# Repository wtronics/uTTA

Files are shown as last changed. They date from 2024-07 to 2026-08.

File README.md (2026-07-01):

# uTTA — The Micro ($\mu$) Thermal Transient Analyzer

## What's this TTA stuff anyhow?

Thermal Transient Analysis (TTA) is an advanced technique used to determine the thermal impedance model of a cooling path by measuring its thermal step response. This method is rigorously specified in the **JESD 51-14** standard and is brilliantly summarized in the following tutorials:
* [Transient thermal measurements and thermal equivalent circuit models](https://www.infineon.com/dgdl/Infineon-Thermal_equivalent_circuit_models-ApplicationNotes-v01_02-EN.pdf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) *(Highly recommended!)*
* [Structure function based evaluation of the thermal behavior of an LED](https://repository.tugraz.at/publications/1bz3b-q3w35) *(Definitely worth to read)*

Ideally, after completing a measurement, you should be able to transform the raw captured data into a thermal impedance ($Z_{th}$) curve—a staple graph found in almost every power semiconductor datasheet. In a nutshell, a $Z_{th}$ curve allows engineers to read the specific thermal resistance encountered by a device when a rectangular power pulse of a given duration $x$ is applied. By combining this thermal resistance with the dissipated power, you can calculate the exact junction temperature of the semiconductor at the end of that pulse. 

However, this math only holds true as long as the power pulse is brief enough not to hit the physical thermal boundaries of the semiconductor package itself. Once the heat propagates past those boundaries and into the rest of the assembly, you need a dedicated thermal impedance curve tailored to your specific, real-world cooling path. Nexperia published an excellent application note diving deeper into this topic: 
* [Nexperia AN11156](https://assets.nexperia.com/documents/application-note/AN11156.pdf)

Things get significantly more complicated when dealing with non-rectangular power pulses. While an "extended rectangular" approximation works for a rough estimate, it demands a massive amount of manual effort. Furthermore, if your ultimate goal is running a dynamic thermal simulation, static datasheet graphs are practically useless. For simulation purposes, the most elegant approach is to model the thermal cooling path using a network of RC circuits that mimic the system's heating and cooling behavior. Again, Nexperia offers a fantastic guide on how this is done: 
* [Nexperia AN11261](https://assets.nexperia.com/documents/application-note/AN11261.pdf)

But how do you actually extract these RC models for a specific power semiconductor combined with a custom heatsink? This is where the real headache begins. While you might occasionally find thermal models for a MOSFET, they are almost exclusively provided as encrypted SPICE models. Nexperia is one of the few refreshing exceptions, sometimes offering open thermal equivalent RC networks (structured as either Foster or Cauer models). But when it comes to the heatsink, manufacturers typically provide nothing more than a single, static thermal resistance value.

---

## How to perform these measurements?
### The Proper (and Expensive) Way
Capturing high-fidelity thermal transient measurements requires highly specialized hardware. The industry standard system is called **T3Ster**, originally engineered by MicReD (a Hungarian company later acquired by Siemens). 

Unsurprisingly, industrial equipment like this costs an absolute fortune—well into the high 5-to-6-figure Euro range. Because such professional tools are completely inaccessible for hobbyist or educational budgets, I set out to design and build my own miniature alternative.

### My own little Thermal Transient Analyzer (uTTA)
uTTA began as a passion project during the first COVID-19 lockdown. At the time, I was experimenting heavily with various power electronics (mostly MOSFET-based power switches and electronic loads) and kept running into the exact same wall: *How long can I dissipate a specific amount of surge power in this MOSFET before it reaches its critical destructive temperature?*

While several theoretical methods exist to solve this, every single one of them requires you to know the exact thermal impedance curve of your unique mechanical setup.

#### Target Picture
The following checklist outlines the core objectives of this project and what has been successfully accomplished so far:
* [x] **Measurement Hardware:** Design a hardware platform capable of performing single-channel thermal impedance measurements while simultaneously monitoring at least 2 additional channels for future thermal coupling analysis.
* [x] **Postprocessing Software:** Build a software toolkit to process raw measurement data and extract clean thermal impedance ($Z_{th}$) curves.
* [x] **Thermal Coupling:** Add software/hardware support to measure thermal coupling between adjacent semiconductors.
* [x] **Self-Calibration:** Implement software utilities to calibrate the internal measurement hardware.
* [ ] **Time Constant Spectra:** Implement the ability to calculate the time constant spectrum of the $Z_{th}$ curve via the NID (Network Identification by Deconvolution) method (utilizing either classical FFT deconvolution or a Bayesian approach).
* [ ] **RC Model Extraction:** Automatically extract equivalent RC thermal networks directly from the calculated time constant spectrum.
* [x] **Junction Calibration:** Develop software and hardware tools to calibrate the temperature coefficient of the junction under test.
* [ ] **Hardware Simulator:** Build a dedicated hardware simulator capable of generating highly predictable and repeatable cooling curves to rigorously validate all subsequent software processing steps.

#### Design Requirements
The device must adhere to the following constraints:
* **User-Friendly:** It should be straightforward and intuitive to operate.
* **Cost-Effective:** Extremely cheap and easy to replicate. Target budget: **€150** covering all components and the PCB.
* **Highly Available:** Rely exclusively on off-the-shelf components; absolutely no hard-to-find or "unobtanium" parts.
* **High-Current Handling:** Integrate an onboard heating current switch rated for up to 15A DC which could be upgraded to even higher heating currents.
* **Auxiliary Sensing:** Include a few Type-K thermocouple interfaces for low-speed ambient/heatsink monitoring (< 5 Samples/s).
* **Multi-Junction Tracking:** Capable of measuring the primary Junction Under Test (JUT) alongside 2 secondary monitoring junctions to evaluate thermal coupling.
* **Dynamic Range Optimization:** Provide software-selectable gain settings for the JUT monitor to maximize ADC resolution throughout the transient event.
* **High-Speed Sampling Speed:** Deliver an ultra-fast sampling rate of at least 1MS/s immediately following the deactivation of the heating current to capture the critical early transient behavior.
* **Intelligent Data Reduction:** Automatically taper down the sampling rate as the transient slows down, preventing the accumulation of massive, redundant data logs.
* **Onboard Storage:** Buffer all high-speed data directly to built-in local memory.
* **PC Control:** Managed entirely via a clean, accessible PC graphical user interface (GUI).

---

# The Implementation

## µTTA Hardware
This is the current physical state of the µTTA hardware. The architecture utilizes a compact 3-layer PCB stack enclosed in a custom 3D-printed housing. The design files for the mechanical housing are available under `010_Hardware/060_Mechanics`.

uTTA_Device_Setup_Annotated

## The Final Test Setup (Simplified)
Below is an overview of the active test setup. The JUT assembly is positioned right next to the power supply. 

> **Note on Environment:** In a professional testing environment, the JUT assembly must be enclosed in a "still air chamber" to isolate the measurement from volatile ambient drafts. Ideally, the device would be mounted onto a temperature-controlled cold plate, but that represents an unnecessary layer of complexity for the scope of this hobby project.

Simple_Test_Setup

The system is composed of the following core blocks:

### The Heating Power Supply
This unit drives the raw heating current through the Junction Under Test (JUT). While I happen to use a massive 40A bench supply in my lab, any standard power supply featuring an adjustable current limit up to 10A is perfectly adequate for most scenarios. 

The exact current required depends heavily on the specific junction properties and the thermal resistance of the cooling assembly under evaluation. If you are targeting a high-power device with ultra-low thermal resistance (e.g., < 10 K/W), a meatier power supply becomes necessary to force a measurable temperature delta. The supply voltage itself is uncritical; in my configurations, I typically set it to roughly 3V, which provides plenty of headroom to comfortably drive the required current.

### The Junction Under Test
*(To be continued...)*

---

## The JUT Setup

Lacking access to a formal industrial application board I can show in public, I assembled a custom test fixture that closely mimics real-world conditions. The setup consists of three spare MOSFETs bolted to a shared aluminum heatsink. 
The transistors are electrically isolated from the heatsink using standard mica ("glimmer") washers and silicone thermal pads. However, to establish a shared return path for the sense current across all monitored devices, the isolating washers on the mounting screws were intentionally omitted to bridge the drains of all three MOSFETs together. The Gate and Source pins of each individual MOSFET are shorted to prevent spurious turn-on events triggered by static charges. 
Furthermore, each MOSFET is routed through a dedicated coaxial sense cable to accurately monitor the forward voltage drop of the internal body diodes and supply the delicate measurement current. The primary heated junction is also hooked up to heavy-gauge wires to carry the high heating current. These low-inductance lines are custom-made by braiding high-frequency (HF) litz wire. To minimize the overall loop area and shield against inductive voltage spikes, the positive and negative current paths are tightly bundled inside a braided insulating sleeve.

JUT_on_Heatsink

# ToDo
- [x] Build calibration GUI for uTTA hardware.
- [x] Build calibration GUI for DUT scaling factors.
- [x] Document ST Nucleo-Board jumper configurations.
- [ ] Get the mathematical deconvolution algorithm fully operational.
- [ ] Implement automatic RC-model calculation from the time constant spectrum.
- [ ] Develop a modern, native standalone GUI (moving away from LabVIEW).
- [ ] Overhaul and expand the general documentation.

# Possible Improvements for Future Designs
- [ ] Implement finer gain steps for low-level diode voltage measurements.
- [x] Integrate software-controlled offset adjustment via an onboard DAC.
- [x] Integrate software-adjustable measurement current sources (e.g., DAC-controlled Enhanced Howland Current Sources).
- [ ] Migrate away from the ST Nucleo breakout ecosystem in favor of a fully custom, integrated PCB design. *(Benefits: Eliminates bulky stack-up connectors, drastically improves high-speed signal integrity, allows a highly stable dedicated ADC voltage reference, and enables a native onboard USB interface bypassing the ST-Link debugger).*

## Design Choices

Let's be candid: this system is far from a flawless commercial product. As stated at the beginning, this started as a quick-and-dirty quarantine project during the COVID-19 pandemic. I never anticipated that I would still be actively evolving it over 6 years later. The subject matter completely hooked me, though personal commitments have limited the amount of focused time I can dedicate to it. Because both the hardware and software architectures have undergone iterative overhauls, some design choices might appear slightly unorthodox to an outside observer. Here is the underlying engineering rationale:

* **Why store measurement data in local flash memory instead of streaming it directly to a PC over a serial interface?**
  * Our serial connection maxes out at 250 kBaud, which is fundamentally incapable of sustaining the throughput required during the initial 1 MS/s ultra-fast sampling window. Additionally, the microcontroller lacks the RAM capacity required to buffer the millions of high-speed points simultaneously before a delayed dump. Therefore, high-speed hardware-level buffering to external non-volatile storage was mandatory. While I initially used a micro SD card running FATfs, the aggressive write cycles quickly destroyed the cards. Upgrading to a robust NOR Flash chip running **littleFS** completely solved this reliability bottleneck.

* **Why is there only one switchable amplifier? Shouldn't every tracking channel have its own dynamic gain stage?**
  * The switchable programmable gain amplifier (PGA) is intentionally reserved for the primary heated channel. When the massive heating current passes through the JUT, its forward voltage is substantially larger due to the internal resistance. The amplifier must dynamically drop its gain down during this phase to prevent clipping and keep the signal within the measurable ADC window. 
  * The secondary channels, by contrast, are strictly passive—they monitor adjacent unheated diodes utilizing a constant, low-level measurement current where no severe voltage swings occur. A fixed gain stage is perfectly sufficient to map standard silicon diodes or MOSFET body diodes across these monitoring channels.

* **Why did you build the original GUI in LabVIEW?**
  * Frankly, because I use it daily in my day job as a self-proclaimed "lazy" senior hardware developer! 😉 In industrial prototyping, test software needs to be deployed rapidly, and that is precisely where LabVIEW excels. 
  * I am well aware that LabVIEW is quite polarizing in the developer community, but for whipping together a functional, interactive GUI without getting bogged down in TKinter or basic UI positioning math, it remains an incredibly fast tool.
  * **Update (July 1, 2026):** The complete postprocessing toolchain has now been successfully migrated to a modern Python ecosystem utilizing `TTKbootstrap`. Consequently, I am officially working on sunsetting the legacy LabVIEW GUI in upcoming releases. The foundational groundwork was recently completed following the development of our native SCPI driver for the uTTA hardware.

* **Why power the gate driver of the high-current heating switch with an external battery instead of a standard bench supply?**
  * In the early prototyping phases, I did use a secondary isolated bench supply to power the gate drive circuitry. However, I found myself locked in an endless, frustrating battle with nasty common-mode noise issues during high-current switching events. Swapping that power rail over to a completely floating 9V/12V battery completely severed the noise path and instantly wiped out all common-mode artifacts.

---

# A Note on AI

Given how pervasive AI has become in modern software development, I wanted to include a brief, transparent disclosure regarding its role in this repository. This project leverages generative AI to accelerate development velocities and explore alternative conceptual approaches. 

To be clear: the core firmware running on the microcontroller is entirely handwritten from scratch. On the host PC side, things are a bit more collaborative. I heavily utilize AI to spin up structural boilerplate, generate templates, and prototype abstract UI concepts. For instance, the clean HTML layout used to compile the final measurement reports was largely authored by AI, as LLMs are remarkably proficient at building attractive front-end layouts. 

That being said, every single line of code or structural layout spat out by an AI is meticulously peer-reviewed by a human before merging. AI tools are notoriously confident when generating bugs; for example, LLMs absolutely love using deprecated syntax or obsolete methods from older versions of `tkinter` and `TTKbootstrap`. Treat it as a highly capable but slightly reckless assistant!

P.S.: This reame was also redacted by AI :).

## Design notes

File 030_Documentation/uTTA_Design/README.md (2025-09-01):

# uTTA - The  (µ) micro Thermal Transient Analyzer Design

The current design consists of 3 PCBs which are stacked on top of each other. This stacked design was chosen to thermally decouple the power part from the measurement part.

uTTA_V2 2_SystemDrawings_Page1

## The power PCB
This is the PCB at the bottom of the stack. It holds all the parts which are somehow related to power. Therefore, on there is the overall power supply for the whole system. The system is fed by a bipolar power supply which should be able to deliver +/-12V with max. 120mA. In addition, on the power PCB there is the main heating current switch and the heating current measurement which is used to switch and measure the heating current trough the JUT. In addition the power PCB holds a CR2032 backup battery which is used to run the RTC of the microcontroller.

uTTA_V2 2_SystemDrawings_Page2

## The Microcontroller PCB
This PCB is an off the shelf STM32F303RE Nucleo-64 Board. During my first tests I found out that the electrolythic capacitors on the power PCB are a little too high (~0.2mm). This causes a big risk of short circuits between the can of the electrolythic caps and some pins of the header rows. Therefore it is highly recommended to trim the pins of header rows CN6, CN8 and CN9 as short as possible to prevent these short. Furthermore it is recommended to remove the push button caps from buttons B1 and B2 as they might be jammed and become staticly pressed by the measure board.

Last but not least the microcontroller PCB is a little modified in terms of jumper settings: 

- Top Side:
  - JP5: E5V
  - JP6: Closed
- Bottom Side:
  - SB45: Open

## The measure PCB
The top most PCB hold everything which is related to measurement. On this PCB there is the Offset voltage reference generator which provides a common offset voltage for all 4 Monitor channels. Then there are 4 so called monitor channels. These channels provide a measurement current of ~1mA to each body diode and sense the voltage drop across the body diode. This voltage drop if amplified and offset with the voltage from the offset generator. Afterwards it is fed into the microcontrollers ADC. In Addition to the monitor channels there are 4 thermocouple transducer ICs MAX6675 to directly convert thermocouple values into temperatures. Finally, there's the FLASH memory on the PCB which is used to save the measurement data during the measurement.

uTTA_V2 2_SystemDrawings_Page3

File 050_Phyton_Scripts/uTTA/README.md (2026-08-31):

# uTTA - Python Scripts Collection

Cross-platform measurement & post-processing tool.

## Quick Start Guide

This project includes an automated setup and launcher script (`install_and_run.py`) that manages the virtual environment, installs dependencies directly from `pyproject.toml`, and runs the application across Windows, macOS, and Linux.

---

### Prerequisites

* **Python 3.11+** installed on your system.
* Internet connection (required for initial setup and dependency installation).

---

### How to Run

1. Open your terminal (**Command Prompt** or **PowerShell** on Windows, **Terminal** on macOS/Linux).
2. Navigate to the project directory:
   ```bash
   cd path/to/uTTA
   ```

3. Run the setup and launcher script:

* Windows:
   ```DOS
   python install_and_run.py
   ```
* macOS/Linux
   ```bash
   python3 install_and_run.py
   ```

## What the Script Does Automatically
* Virtual Environment Setup: Detects whether a local environment (```.venv/```) exists. If missing, it creates one automatically.
* Dependency Management: Reads ```pyproject.toml``` and installs or updates all required Python packages with live progress in the console.
* Script Discovery & Execution:
   * If only one ```.py```/```.pyw``` script is present in the directory, it launches automatically.
   * If multiple scripts are found, an interactive menu allows you to select which script to execute.

* Logging: All execution output and setup steps are simultaneously printed to the console and saved to ```install_log.txt``` for troubleshooting.

## File Structure
* ```install_and_run.py``` - Cross-platform launcher and setup script.
* ```pyproject.toml``` - Project configuration and dependency definitions.
* ```install_log.txt``` - Log file generated automatically during setup and execution.
* ```.venv/``` - Local virtual environment (created on first run).

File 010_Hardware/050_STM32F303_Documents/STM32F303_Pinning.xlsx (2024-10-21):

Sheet: IO-Table
LQFP64 | Pin Name | Pin Type | I/O Structure | Notes | Alternate Function | Attached Signal | Function Used | Pin Used | Avail on Morpho
1 | VBAT | S | - | - | - | VDD | 12 | 1 | CN7.33
2 | PC13(2) | I/O | TC | - | [PC13] GPIO | B1 - PushButton | 1 | 1 | CN7.23
2 | PC13(2) | I/O | TC | - | EVENTOUT |  | 0 | 1 | CN7.23
2 | PC13(2) | I/O | TC | - | TIM1_CH1N |  | 0 | 1 | CN7.23
2 | PC13(2) | I/O | TC | - | WKUP2 |  | 0 | 1 | CN7.23
2 | PC13(2) | I/O | TC | - | RTC_TAMP1 |  | 0 | 1 | CN7.23
2 | PC13(2) | I/O | TC | - | RTC_TS |  | 0 | 1 | CN7.23
2 | PC13(2) | I/O | TC | - | RTC_OUT |  | 0 | 1 | CN7.23
3 | PC14 - OSC32_IN | I/O | TC | - | [PC14] GPIO |  | 0 | 1 | CN7.25
3 | PC14 - OSC32_IN | I/O | TC | - | EVENTOUT |  | 0 | 1 | CN7.25
3 | PC14 - OSC32_IN | I/O | TC | - | OSC32_IN | RCC_OSC32_IN | 1 | 1 | CN7.25
4 | PC15 - OSC32_OUT(2) | I/O | TC | - | [PC15] GPIO |  | 0 | 1 | CN7.27
4 | PC15 - OSC32_OUT(2) | I/O | TC | - | EVENTOUT |  | 0 | 1 | CN7.27
4 | PC15 - OSC32_OUT(2) | I/O | TC | - | OSC32_OUT | RCC_OSC32_OUT | 1 | 1 | CN7.27
5 | PF0-OSC_IN | I | FTf | - | [PF0] GPIO |  | 0 | 1 | CN7.29
5 | PF0-OSC_IN | I | FTf | - | EVENTOUT |  | 0 | 1 | CN7.29
5 | PF0-OSC_IN | I | FTf | - | I2C2_SDA |  | 0 | 1 | CN7.29
5 | PF0-OSC_IN | I | FTf | - | SPI2_NSS/I2S2_WS |  | 0 | 1 | CN7.29
5 | PF0-OSC_IN | I | FTf | - | TIM1_CH3N |  | 0 | 1 | CN7.29
5 | PF0-OSC_IN | I | FTf | - | OSC_IN | RCC_OSC_IN | 1 | 1 | CN7.29
6 | PF1 - OSC_OUT | O | FTf | - | [PF1] GPIO |  | 0 | 1 | CN7.31
6 | PF1 - OSC_OUT | O | FTf | - | EVENTOUT |  | 0 | 1 | CN7.31
6 | PF1 - OSC_OUT | O | FTf | - | I2C2_SCL |  | 0 | 1 | CN7.31
6 | PF1 - OSC_OUT | O | FTf | - | SPI2_SCK/I2S2_CK |  | 0 | 1 | CN7.31
6 | PF1 - OSC_OUT | O | FTf | - | OSC_OUT | RCC_OSC_OUT | 1 | 1 | CN7.31
7 | NRST | I-O | RST | - | Device reset input/internal reset output (active low) | RESET | 1 | 1 | CN7.14
8 | PC0 | I/O | TTa | - | [PC0] GPIO | DBG_IO1 | 1 | 1 | CN7.38
8 | PC0 | I/O | TTa | - | EVENTOUT |  | 0 | 1 | CN7.38
8 | PC0 | I/O | TTa | - | TIM1_CH1 |  | 0 | 1 | CN7.38
8 | PC0 | I/O | TTa | - | ADC12_IN6 |  | 0 | 1 | CN7.38
8 | PC0 | I/O | TTa | - | COMP7_INM |  | 0 | 1 | CN7.38
9 | PC1 | I/O | TTa | - | [PC1] GPIO | DBG_IO2 | 1 | 1 | CN7.36
9 | PC1 | I/O | TTa | - | EVENTOUT |  | 0 | 1 | CN7.36
9 | PC1 | I/O | TTa | - | TIM1_CH2 |  | 0 | 1 | CN7.36
9 | PC1 | I/O | TTa | - | ADC12_IN7 |  | 0 | 1 | CN7.36
9 | PC1 | I/O | TTa | - | COMP7_INP |  | 0 | 1 | CN7.36
10 | PC2 | I/O | TTa | - | [PC2] GPIO | DBG_IO3 | 1 | 1 | CN7.35
10 | PC2 | I/O | TTa | - | EVENTOUT |  | 0 | 1 | CN7.35
10 | PC2 | I/O | TTa | - | TIM1_CH3 |  | 0 | 1 | CN7.35
10 | PC2 | I/O | TTa | - | COMP7_OUT |  | 0 | 1 | CN7.35
10 | PC2 | I/O | TTa | - | ADC12_IN8 |  | 0 | 1 | CN7.35
11 | PC3 | I/O | TTa | - | [PC3] GPIO | DBG_IO4 | 1 | 1 | CN7.37
11 | PC3 | I/O | TTa | - | EVENTOUT |  | 0 | 1 | CN7.37
11 | PC3 | I/O | TTa | - | TIM1_CH4 |  | 0 | 1 | CN7.37
11 | PC3 | I/O | TTa | - | TIM1_BKIN2 |  | 0 | 1 | CN7.37
11 | PC3 | I/O | TTa | - | ADC12_IN9 |  | 0 | 1 | CN7.37
12 | VSSA | S | - | -1 | - | VSS | 12 | 1 | CN10.32
13 | VDDA | S | - | - | - | VDD | 12 | 1 | CN10.7
14 | PA0 | I/O | TTa | - | [PA0] GPIO | PWSTG_ENABLE_DO | 1 | 1 | CN7.28
14 | PA0 | I/O | TTa | - | TIM2_CH1/TIM2_ETR |  | 0 | 1 | CN7.28
14 | PA0 | I/O | TTa | - | TSC_G1_IO1 |  | 0 | 1 | CN7.28
14 | PA0 | I/O | TTa | - | USART2_CTS |  | 0 | 1 | CN7.28
14 | PA0 | I/O | TTa | - | COMP1_OUT |  | 0 | 1 | CN7.28
14 | PA0 | I/O | TTa | - | TIM8_BKIN |  | 0 | 1 | CN7.28
14 | PA0 | I/O | TTa | - | TIM8_ETR |  | 0 | 1 | CN7.28
14 | PA0 | I/O | TTa | - | EVENTOUT |  | 0 | 1 | CN7.28
14 | PA0 | I/O | TTa | - | ADC1_IN1(3) |  | 0 | 1 | CN7.28
14 | PA0 | I/O | TTa | - | COMP1_INM |  | 0 | 1 | CN7.28
14 | PA0 | I/O | TTa | - | RTC_TAMP2 |  | 0 | 1 | CN7.28
14 | PA0 | I/O | TTa | - | WKUP1 |  | 0 | 1 | CN7.28
15 | PA1 | I/O | TTa | - | [PA1] GPIO | PWSTG_UVLO_DI | 1 | 1 | CN7.30
15 | PA1 | I/O | TTa | - | RTC_REFIN |  | 0 | 1 | CN7.30
15 | PA1 | I/O | TTa | - | TIM2_CH2 |  | 0 | 1 | CN7.30
15 | PA1 | I/O | TTa | - | TSC_G1_IO2 |  | 0 | 1 | CN7.30
15 | PA1 | I/O | TTa | - | USART2_RTS |  | 0 | 1 | CN7.30
15 | PA1 | I/O | TTa | - | TIM15_CH1N |  | 0 | 1 | CN7.30
15 | PA1 | I/O | TTa | - | EVENTOUT |  | 0 | 1 | CN7.30
15 | PA1 | I/O | TTa | - | ADC1_IN2(3) |  | 0 | 1 | CN7.30
15 | PA1 | I/O | TTa | - | COMP1_INP |  | 0 | 1 | CN7.30
15 | PA1 | I/O | TTa | - | OPAMP1_VINP |  | 0 | 1 | CN7.30
15 | PA1 | I/O | TTa | - | OPAMP3_VINP |  | 0 | 1 | CN7.30
16 | PA2 | I/O | TTa | -5 | [PA2] GPIO |  | 0 | 1 | CN10.35
16 | PA2 | I/O | TTa | -5 | TIM2_CH3 |  | 0 | 1 | CN10.35
16 | PA2 | I/O | TTa | -5 | TSC_G1_IO3 |  | 0 | 1 | CN10.35
16 | PA2 | I/O | TTa | -5 | USART2_TX | USART_TX | 1 | 1 | CN10.35
16 | PA2 | I/O | TTa | -5 | COMP2_OUT |  | 0 | 1 | CN10.35
16 | PA2 | I/O | TTa | -5 | TIM15_CH1 |  | 0 | 1 | CN10.35
16 | PA2 | I/O | TTa | -5 | EVENTOUT |  | 0 | 1 | CN10.35
16 | PA2 | I/O | TTa | -5 | ADC1_IN3(3) |  | 0 | 1 | CN10.35
16 | PA2 | I/O | TTa | -5 | COMP2_INM |  | 0 | 1 | CN10.35
16 | PA2 | I/O | TTa | -5 | OPAMP1_VOUT |  | 0 | 1 | CN10.35
17 | PA3 | I/O | TTa | - | [PA3] GPIO |  | 0 | 1 | CN10.37
17 | PA3 | I/O | TTa | - | TIM2_CH4 |  | 0 | 1 | CN10.37
17 | PA3 | I/O | TTa | - | TSC_G1_IO4 |  | 0 | 1 | CN10.37
17 | PA3 | I/O | TTa | - | USART2_RX | USART_RX | 1 | 1 | CN10.37
17 | PA3 | I/O | TTa | - | TIM15_CH2 |  | 0 | 1 | CN10.37
17 | PA3 | I/O | TTa | - | EVENTOUT |  | 0 | 1 | CN10.37
17 | PA3 | I/O | TTa | - | ADC1_IN4(3) |  | 0 | 1 | CN10.37
17 | PA3 | I/O | TTa | - | OPAMP1_VINM |  | 0 | 1 | CN10.37
17 | PA3 | I/O | TTa | - | OPAMP1_VINP |  | 0 | 1 | CN10.37
18 | VSS | S | - | - | - | VSS | 12 | 4
19 | VDD | S | - | -1 | - | VDD | 12 | 4
20 | PA4 | I/O | TTa | -5 | [PA4] GPIO | PSU_ENABLE_DO | 1 | 1 | CN7.32
20 | PA4 | I/O | TTa | -5 | TIM3_CH2 |  | 0 | 1 | CN7.32
20 | PA4 | I/O | TTa | -5 | TSC_G2_IO1 |  | 0 | 1 | CN7.32
20 | PA4 | I/O | TTa | -5 | SPI1_NSS |  | 0 | 1 | CN7.32
20 | PA4 | I/O | TTa | -5 | SPI3_NSS/I2S3_WS |  | 0 | 1 | CN7.32
20 | PA4 | I/O | TTa | -5 | USART2_CK |  | 0 | 1 | CN7.32
20 | PA4 | I/O | TTa | -5 | EVENTOUT |  | 0 | 1 | CN7.32
20 | PA4 | I/O | TTa | -5 | ADC2_IN1(3) |  | 0 | 1 | CN7.32
20 | PA4 | I/O | TTa | -5 | DAC1_OUT1 |  | 0 | 1 | CN7.32
20 | PA4 | I/O | TTa | -5 | COMP1_INM |  | 0 | 1 | CN7.32
20 | PA4 | I/O | TTa | -5 | COMP2_INM |  | 0 | 1 | CN7.32
20 | PA4 | I/O | TTa | -5 | COMP3_INM |  | 0 | 1 | CN7.32
20 | PA4 | I/O | TTa | -5 | COMP4_INM |  | 0 | 1 | CN7.32
20 | PA4 | I/O | TTa | -5 | COMP5_INM |  | 0 | 1 | CN7.32
20 | PA4 | I/O | TTa | -5 | COMP6_INM |  | 0 | 1 | CN7.32
20 | PA4 | I/O | TTa | -5 | COMP7_INM |  | 0 | 1 | CN7.32
20 | PA4 | I/O | TTa | -5 | OPAMP4_VINP |  | 0 | 1 | CN7.32
21 | PA5 | I/O | TTa | -5 | [PA5] GPIO | LE2 -LED | 1 | 1 | CN10.11
21 | PA5 | I/O | TTa | -5 | TIM2_CH1/TIM2_ETR |  | 0 | 1 | CN10.11
21 | PA5 | I/O | TTa | -5 | TSC_G2_IO2 |  | 0 | 1 | CN10.11
21 | PA5 | I/O | TTa | -5 | SPI1_SCK |  | 0 | 1 | CN10.11
21 | PA5 | I/O | TTa | -5 | EVENTOUT |  | 0 | 1 | CN10.11
21 | PA5 | I/O | TTa | -5 | ADC2_IN2(3) |  | 0 | 1 | CN10.11
21 | PA5 | I/O | TTa | -5 | DAC1_OUT2 |  | 0 | 1 | CN10.11
21 | PA5 | I/O | TTa | -5 | COMP1_INM |  | 0 | 1 | CN10.11
21 | PA5 | I/O | TTa | -5 | COMP2_INM |  | 0 | 1 | CN10.11
21 | PA5 | I/O | TTa | -5 | COMP3_INM |  | 0 | 1 | CN10.11
21 | PA5 | I/O | TTa | -5 | COMP4_INM |  | 0 | 1 | CN10.11
21 | PA5 | I/O | TTa | -5 | COMP5_INM |  | 0 | 1 | CN10.11
21 | PA5 | I/O | TTa | -5 | COMP6_INM |  | 0 | 1 | CN10.11
21 | PA5 | I/O | TTa | -5 | COMP7_INM |  | 0 | 1 | CN10.11
21 | PA5 | I/O | TTa | -5 | OPAMP1_VINP |  | 0 | 1 | CN10.11
21 | PA5 | I/O | TTa | -5 | OPAMP2_VINM |  | 0 | 1 | CN10.11
21 | PA5 | I/O | TTa | -5 | OPAMP3_VINP |  | 0 | 1 | CN10.11
22 | PA6 | I/O | TTa | -5 | [PA6] GPIO | GAIN_B0_DO | 1 | 1 | CN10.13
22 | PA6 | I/O | TTa | -5 | TIM16_CH1 |  | 0 | 1 | CN10.13
22 | PA6 | I/O | TTa | -5 | TIM3_CH1 |  | 0 | 1 | CN10.13
22 | PA6 | I/O | TTa | -5 | TSC_G2_IO3 |  | 0 | 1 | CN10.13
22 | PA6 | I/O | TTa | -5 | TIM8_BKIN |  | 0 | 1 | CN10.13
22 | PA6 | I/O | TTa | -5 | SPI1_MISO |  | 0 | 1 | CN10.13
22 | PA6 | I/O | TTa | -5 | TIM1_BKIN |  | 0 | 1 | CN10.13
22 | PA6 | I/O | TTa | -5 | COMP1_OUT |  | 0 | 1 | CN10.13
22 | PA6 | I/O | TTa | -5 | EVENTOUT |  | 0 | 1 | CN10.13
22 | PA6 | I/O | TTa | -5 | ADC2_IN3(3) |  | 0 | 1 | CN10.13
22 | PA6 | I/O | TTa | -5 | OPAMP2_VOUT |  | 0 | 1 | CN10.13
23 | PA7 | I/O | TTa | - | [PA7] GPIO | GAIN_B1_DO | 1 | 1 | CN10.15
23 | PA7 | I/O | TTa | - | TIM17_CH1 |  | 0 | 1 | CN10.15
23 | PA7 | I/O | TTa | - | TIM3_CH2 |  | 0 | 1 | CN10.15
23 | PA7 | I/O | TTa | - | TSC_G2_IO4 |  | 0 | 1 | CN10.15
23 | PA7 | I/O | TTa | - | TIM8_CH1N |  | 0 | 1 | CN10.15
23 | PA7 | I/O | TTa | - | SPI1_MOSI |  | 0 | 1 | CN10.15
23 | PA7 | I/O | TTa | - | TIM1_CH1N |  | 0 | 1 | CN10.15
23 | PA7 | I/O | TTa | - | EVENTOUT |  | 0 | 1 | CN10.15
23 | PA7 | I/O | TTa | - | ADC2_IN4(3) |  | 0 | 1 | CN10.15
23 | PA7 | I/O | TTa | - | COMP2_INP |  | 0 | 1 | CN10.15
23 | PA7 | I/O | TTa | - | OPAMP1_VINP |  | 0 | 1 | CN10.15
23 | PA7 | I/O | TTa | - | OPAMP2_VINP |  | 0 | 1 | CN10.15
24 | PC4 | I/O | TTa | - | [PC4] GPIO |  | 0 | 0 | CN10.34
24 | PC4 | I/O | TTa | - | EVENTOUT |  | 0 | 0 | CN10.34
24 | PC4 | I/O | TTa | - | TIM1_ETR |  | 0 | 0 | CN10.34
24 | PC4 | I/O | TTa | - | USART1_TX |  | 0 | 0 | CN10.34
24 | PC4 | I/O | TTa | - | ADC2_IN5(3) |  | 0 | 0 | CN10.34
25 | PC5 | I/O | TTa | - | [PC5] GPIO | TEMP_SPI_CSN1 | 1 | 1 | CN10.6
25 | PC5 | I/O | TTa | - | EVENTOUT |  | 0 | 1 | CN10.6
25 | PC5 | I/O | TTa | - | TIM15_BKIN |  | 0 | 1 | CN10.6
25 | PC5 | I/O | TTa | - | TSC_G3_IO1 |  | 0 | 1 | CN10.6
25 | PC5 | I/O | TTa | - | USART1_RX |  | 0 | 1 | CN10.6
25 | PC5 | I/O | TTa | - | ADC2_IN11 |  | 0 | 1 | CN10.6
25 | PC5 | I/O | TTa | - | OPAMP1_VINM |  | 0 | 1 | CN10.6
25 | PC5 | I/O | TTa | - | OPAMP2_VINM |  | 0 | 1 | CN10.6
26 | PB0 | I/O | TTa | - | [PB0] GPIO | PWSTG_PWR_EN_DO | 1 | 1 | CN7.34
26 | PB0 | I/O | TTa | - | TIM3_CH3 |  | 0 | 1 | CN7.34
26 | PB0 | I/O | TTa | - | TSC_G3_IO2 |  | 0 | 1 | CN7.34
26 | PB0 | I/O | TTa | - | TIM8_CH2N |  | 0 | 1 | CN7.34
26 | PB0 | I/O | TTa | - | TIM1_CH2N |  | 0 | 1 | CN7.34
26 | PB0 | I/O | TTa | - | EVENTOUT |  | 0 | 1 | CN7.34
26 | PB0 | I/O | TTa | - | ADC3_IN12 |  | 0 | 1 | CN7.34
26 | PB0 | I/O | TTa | - | COMP4_INP |  | 0 | 1 | CN7.34
26 | PB0 | I/O | TTa | - | OPAMP2_VINP |  | 0 | 1 | CN7.34
26 | PB0 | I/O | TTa | - | OPAMP3_VINP |  | 0 | 1 | CN7.34
27 | PB1 | I/O | TTa | -5 | [PB1] GPIO |  | 0 | 1 | CN10.24
27 | PB1 | I/O | TTa | -5 | TIM3_CH4 |  | 0 | 1 | CN10.24
27 | PB1 | I/O | TTa | -5 | TSC_G3_IO3 |  | 0 | 1 | CN10.24
27 | PB1 | I/O | TTa | -5 | TIM8_CH3N |  | 0 | 1 | CN10.24
27 | PB1 | I/O | TTa | -5 | TIM1_CH3N |  | 0 | 1 | CN10.24
27 | PB1 | I/O | TTa | -5 | COMP4_OUT |  | 0 | 1 | CN10.24
27 | PB1 | I/O | TTa | -5 | EVENTOUT |  | 0 | 1 | CN10.24
27 | PB1 | I/O | TTa | -5 | ADC3_IN1(3) | PGA_DIODE3_OUT | 1 | 1 | CN10.24
27 | PB1 | I/O | TTa | -5 | OPAMP3_VOUT |  | 0 | 1 | CN10.24
28 | PB2 | I/O | TTa | - | [PB2] GPIO |  | 0 | 1 | CN10.22
28 | PB2 | I/O | TTa | - | TSC_G3_IO4 |  | 0 | 1 | CN10.22
28 | PB2 | I/O | TTa | - | EVENTOUT |  | 0 | 1 | CN10.22
28 | PB2 | I/O | TTa | - | ADC2_IN12 | PGA_DIODE2_OUT | 1 | 1 | CN10.22
28 | PB2 | I/O | TTa | - | COMP4_INM |  | 0 | 1 | CN10.22
28 | PB2 | I/O | TTa | - | OPAMP3_VINM |  | 0 | 1 | CN10.22
29 | PB10 | I/O | TTa | - | [PB10] GPIO |  | 0 | 0 | CN10.25
29 | PB10 | I/O | TTa | - | TIM2_CH3 |  | 0 | 0 | CN10.25
29 | PB10 | I/O | TTa | - | TSC_SYNC |  | 0 | 0 | CN10.25
29 | PB10 | I/O | TTa | - | USART3_TX |  | 0 | 0 | CN10.25
29 | PB10 | I/O | TTa | - | EVENTOUT |  | 0 | 0 | CN10.25
29 | PB10 | I/O | TTa | - | COMP5_INM |  | 0 | 0 | CN10.25
29 | PB10 | I/O | TTa | - | OPAMP3_VINM |  | 0 | 0 | CN10.25
29 | PB10 | I/O | TTa | - | OPAMP4_VINM |  | 0 | 0 | CN10.25
30 | PB11 | I/O | TTa | - | [PB11] GPIO |  | 0 | 1 | CN10.18
30 | PB11 | I/O | TTa | - | TIM2_CH4 |  | 0 | 1 | CN10.18
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

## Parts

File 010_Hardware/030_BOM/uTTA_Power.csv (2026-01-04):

Part | Value | Device | Package | Description | I_OUT | MF | MPN | OC_FARNELL | OC_NEWARK | PACKAGE | R1 | R2
C1 | 22n/25V | C-EUC0603 | C0603 | CAPACITOR, European symbol |  |  |  |  |  | C0603
C2 | 1000uF/16V | CPOL-EUE5-10.5 | E5-10,5 | POLARIZED CAPACITOR, European symbol
C3 | 1000uF/16V | CPOL-EUE5-10.5 | E5-10,5 | POLARIZED CAPACITOR, European symbol
C4 | 1000uF/16V | CPOL-EUE5-10.5 | E5-10,5 | POLARIZED CAPACITOR, European symbol
C5 | 1n/25V | C-EUC0603 | C0603 | CAPACITOR, European symbol |  |  |  |  |  | C0603
C101 | 47µF/25V | CPOL-EUD | PANASONIC_D | POLARIZED CAPACITOR, European symbol
C102 | 100n/50V | C-EUC0805 | C0805 | CAPACITOR, European symbol |  |  |  |  |  | C0805
C103 | 47u/35V | CPOL-EUD | PANASONIC_D | POLARIZED CAPACITOR, European symbol
C104 | 47u/35V | CPOL-EUD | PANASONIC_D | POLARIZED CAPACITOR, European symbol
C105 | 100n/50V | C-EUC0805 | C0805 | CAPACITOR, European symbol |  |  |  |  |  | C0805
C106 | 100n/50V | C-EUC0805 | C0805 | CAPACITOR, European symbol |  |  |  |  |  | C0805
C107 | 100n/50V | C-EUC0805 | C0805 | CAPACITOR, European symbol |  |  |  |  |  | C0805
C108 | 100n/50V | C-EUC0805 | C0805 | CAPACITOR, European symbol |  |  |  |  |  | C0805
C109 | 100n/50V | C-EUC0805 | C0805 | CAPACITOR, European symbol |  |  |  |  |  | C0805
C110 | 100n/50V | C-EUC0805 | C0805 | CAPACITOR, European symbol |  |  |  |  |  | C0805
C111 | 100n/50V | C-EUC0805 | C0805 | CAPACITOR, European symbol |  |  |  |  |  | C0805
C112 | 100n/50V | C-EUC0805 | C0805 | CAPACITOR, European symbol |  |  |  |  |  | C0805
C113 | 100n/50V | C-EUC0805 | C0805 | CAPACITOR, European symbol |  |  |  |  |  | C0805
C114 | 100n/50V | C-EUC0805 | C0805 | CAPACITOR, European symbol |  |  |  |  |  | C0805
C115 | 10u/16V | C-EUC0805 | C0805 | CAPACITOR, European symbol |  |  |  |  |  | C0805
C116 | 10u/16V | C-EUC0805 | C0805 | CAPACITOR, European symbol |  |  |  |  |  | C0805
C119 | 100nF/50V | C-EUC1206 | C1206 | CAPACITOR, European symbol |  |  |  |  |  | C1206
C120 | 100nF/50V | C-EUC1206 | C1206 | CAPACITOR, European symbol |  |  |  |  |  | C1206
C121 | 100nF/50V | C-EUC1206 | C1206 | CAPACITOR, European symbol |  |  |  |  |  | C1206
D1 | BAT46W | DIODE-SOD123 | SOD123 | DIODE |  |  |  |  |  | SOD-123
D101 | 1N4148 | DIODE-SOD123 | SOD123 | DIODE |  |  |  |  |  | SOD-123
D102 | 1N4148 | DIODE-SOD123 | SOD123 | DIODE |  |  |  |  |  | SOD-123
D103 | BZX84B3V9 | BZX84B | SOT23 |  |  |  |  |  |  | SOT-23
D104 | VS-30BQ040 | DIODE-SMC | SMC | DIODE |  |  |  |  |  | SMB
G1 | CR2032H | CR2032H | CR2032H | LI BATTERY Varta
G101 | AB9V | AB9V | AB9V | 9-V BATTERY CLIP
IC1 | MCP14E09 | MCP14E09 | SO-08 |  |  |  |  |  |  | SO-8
IC2 | SFH6156 | SFH6156 | SFH | 5.3 kV TRIOS High Reliability Optocoupler |  | VISHAY/TELEFUNKEN | SFH6156-4T | 1612479 | 21H7733
IC3 | SFH6156 | SFH6156 | SFH | 5.3 kV TRIOS High Reliability Optocoupler |  | VISHAY/TELEFUNKEN | SFH6156-4T | 1612479 | 21H7733
IC4 | SFH6156 | SFH6156 | SFH | 5.3 kV TRIOS High Reliability Optocoupler |  | VISHAY/TELEFUNKEN | SFH6156-4T | 1612479 | 21H7733
IC101 | 78L05SMD | 78L08SMD | SO08 | Positive VOLTAGE REGULATOR |  |  |  |  |  | SO-8
IC102 | 7905ACM | 7905ACM | SO08 | Negative VOLTAGE REGULATOR |  |  |  |  |  | SO-8
IC103 | LM393D | LM393D | SO08 | COMPARATOR |  |  |  |  |  | SO-8
IC105 | LT1167 | LT1167 | SO08 |  |  |  |  |  |  | SO-8
J102 | PIN23866A.68 | PIN23866A.68 | VOGT_3866A.68 | Flachstecker Typ Tyco/Electronics/AMP TAB, FASTON
J103 | PIN23866A.68 | PIN23866A.68 | VOGT_3866A.68 | Flachstecker Typ Tyco/Electronics/AMP TAB, FASTON
J106 | PIN23866A.68 | PIN23866A.68 | VOGT_3866A.68 | Flachstecker Typ Tyco/Electronics/AMP TAB, FASTON
J107 | PIN23866A.68 | PIN23866A.68 | VOGT_3866A.68 | Flachstecker Typ Tyco/Electronics/AMP TAB, FASTON
LED1 | GREEN | LEDSML0805 | SML0805 | LED
LED2 | GREEN | LEDSML0805 | SML0805 | LED
LED101 |  | LEDSML0805 | SML0805 | LED
LED102 |  | LEDSML0805 | SML0805 | LED
LED103 |  | LEDSML0805 | SML0805 | LED
OK1 | HCPL0500 | HCPL0500 | SOIC08 | HEWLETT PACKARD OPTO COUPLER |  | AGILENT TECHNOLOGIES | HCPL-0500-000E | 9995226 | 31K6926
Q1 | IRLML5203 | IRLML5203 | MICRO3 | HEXFET P-Channel Power MOSFET |  |  |  |  |  | SOT-23
Q101 | TSM033NB04 | TSM033NB04CR | PDFN56 | N-Ch MOSFET |  |  |  |  |  | PDFN56
Q102 | TSM033NB04 | TSM033NB04CR | PDFN56 | N-Ch MOSFET |  |  |  |  |  | PDFN56
Q103 | TSM033NB04 | TSM033NB04CR | PDFN56 | N-Ch MOSFET |  |  |  |  |  | PDFN56
Q104 | TSM033NB04 | TSM033NB04CR | PDFN56 | N-Ch MOSFET |  |  |  |  |  | PDFN56
Q105 | TSM033NB04 | TSM033NB04CR | PDFN56 | N-Ch MOSFET |  |  |  |  |  | PDFN56
Q106 | TSM033NB04 | TSM033NB04CR | PDFN56 | N-Ch MOSFET |  |  |  |  |  | PDFN56
Q107 | TSM033NB04 | TSM033NB04CR | PDFN56 | N-Ch MOSFET |  |  |  |  |  | PDFN56
Q108 | TSM033NB04 | TSM033NB04CR | PDFN56 | N-Ch MOSFET |  |  |  |  |  | PDFN56
R1 | 1k5 | R-EU_R0603 | R0603 | RESISTOR, European symbol |  |  |  |  |  | R0603
R2 | 1k5 | R-EU_R0603 | R0603 | RESISTOR, European symbol |  |  |  |  |  | R0603
R3 | 1k | R-EU_R0603 | R0603 | RESISTOR, European symbol |  |  |  |  |  | R0603
R4 | 22R | R-EU_R1206 | R1206 | RESISTOR, European symbol |  |  |  |  |  | R1206
R5 | 22R | R-EU_R1206 | R1206 | RESISTOR, European symbol |  |  |  |  |  | R1206
R6 | 22R | R-EU_R1206 | R1206 | RESISTOR, European symbol |  |  |  |  |  | R1206
R7 | 10k | R-EU_R0603 | R0603 | RESISTOR, European symbol |  |  |  |  |  | R0603
R9 | 10k | R-EU_R0603 | R0603 | RESISTOR, European symbol |  |  |  |  |  | R0603
R101 | 0R | R-EU_R0805 | R0805 | RESISTOR, European symbol |  |  |  |  |  | R0805
R102 | 0R | R-EU_R0805 | R0805 | RESISTOR, European symbol |  |  |  |  |  | R0805
R103 | 10k | R-EU_R0603 | R0603 | RESISTOR, European symbol |  |  |  |  |  | R0603
R104 | 22k | R-EU_R0603 | R0603 | RESISTOR, European symbol |  |  |  |  |  | R0603
R105 | 10k | R-EU_R0603 | R0603 | RESISTOR, European symbol |  |  |  |  |  | R0603
R106 | 680 | R-EU_R0603 | R0603 | RESISTOR, European symbol |  |  |  |  |  | R0603
R107 | 12k | R-EU_R0603 | R0603 | RESISTOR, European symbol |  |  |  |  |  | R0603
R108 | 240R | R-EU_R0603 | R0603 | RESISTOR, European symbol |  |  |  |  |  | R0603
R110 | 470R | R-EU_R0603 | R0603 | RESISTOR, European symbol |  |  |  |  |  | R0603
R111 | 120k | R-EU_R0603 | R0603 | RESISTOR, European symbol |  |  |  |  |  | R0603
R112 | 1k | R-EU_R0603 | R0603 | RESISTOR, European symbol |  |  |  |  |  | R0603
R113 | 10k | R-EU_R0603 | R0603 | RESISTOR, European symbol |  |  |  |  |  | R0603
R114 | 1k5 | R-EU_R0603 | R0603 | RESISTOR, European symbol |  |  |  |  |  | R0603
R115 | 10k | R-EU_R0603 | R0603 | RESISTOR, European symbol |  |  |  |  |  | R0603
R116 | 1k2 | R-EU_R0603 | R0603 | RESISTOR, European symbol |  |  |  |  |  | R0603
R117 | 100R | R-EU_R0603 | R0603 | RESISTOR, European symbol |  |  |  |  |  | R0603
R118 | 10R | R-EU_R0603 | R0603 | RESISTOR, European symbol |  |  |  |  |  | R0603
R120 | n.c. | R-EU_R0603 | R0603 | RESISTOR, European symbol |  |  |  |  |  | R0603
R121 | 100R | R-EU_R0603 | R0603 | RESISTOR, European symbol |  |  |  |  |  | R0603
R122 | 1k | R-EU_R0603 | R0603 | RESISTOR, European symbol |  |  |  |  |  | R0603
R123 | 10R | R-EU_R0603 | R0603 | RESISTOR, European symbol |  |  |  |  |  | R0603
R124 | 10R | R-EU_R0603 | R0603 | RESISTOR, European symbol |  |  |  |  |  | R0603
R125 | 4m | WSL2512 | R2512 |  |  |  |  |  |  | R2512
R126 | DNP | R-EU_R0603 | R0603 | RESISTOR, European symbol |  |  |  |  |  | R0603
R127 | DNP | R-EU_R0603 | R0603 | RESISTOR, European symbol |  |  |  |  |  | R0603
R128 | DNP | WSL2512 | R2512 |  |  |  |  |  |  | R2512
S101 | SS_ESP101 | SS_ESP101 | SS_ESP101
T1 | PDTC143E | PDTC143E | SOT23 | NPN Resistor equipped transistors | 100mA |  |  |  |  | SOT-23 | 4.7k | 4.7k
T3 | PDTC143E | PDTC143E | SOT23 | NPN Resistor equipped transistors | 100mA |  |  |  |  | SOT-23 | 4.7k | 4.7k
T101 | PDTC143E | PDTC143E | SOT23 | NPN Resistor equipped transistors | 100mA |  |  |  |  | SOT-23 | 4.7k | 4.7k
T102 | PDTC143E | PDTC143E | SOT23 | NPN Resistor equipped transistors | 100mA |  |  |  |  | SOT-23 | 4.7k | 4.7k
TP1 | TPC90H30 | TPC90H30 | C90H30
TP2 | TPC90H30 | TPC90H30 | C90H30
TP3 | TPC90H30 | TPC90H30 | C90H30
TP4 | TPC90H30 | TPC90H30 | C90H30
TP5 | TPC90H30 | TPC90H30 | C90H30
TP6 | TPC90H30 | TPC90H30 | C90H30
TP101 | TPC90H30 | TPC90H30 | C90H30
TP102 | TPC90H30 | TPC90H30 | C90H30
TP103 | TPC90H30 | TPC90H30 | C90H30
TP104 | TPC90H30 | TPC90H30 | C90H30
TP105 | TPC90H30 | TPC90H30 | C90H30
TP106 | TPC90H30 | TPC90H30 | C90H30
TP107 | TPC90H30 | TPC90H30 | C90H30
TP108 | TPC90H30 | TPC90H30 | C90H30
TP109 | TPC90H30 | TPC90H30 | C90H30
TP110 | TPC90H30 | TPC90H30 | C90H30
TP111 | TPC90H30 | TPC90H30 | C90H30
TP112 | TPC90H30 | TPC90H30 | C90H30
TP113 | TP | TP | C90
TP114 | TP | TP | C90
TP115 | TPC90H30 | TPC90H30 | C90H30
TP116 | TPC90H30 | TPC90H30 | C90H30
TP117 | TPC90H30 | TPC90H30 | C90H30
TP118 | TPC90H30 | TPC90H30 | C90H30
U201 | NUCLEO_F103_BOT | NUCLEO_F103_BOT | NUCLEO_BRD64_LOWER
X1 | AST_02_3,5MM_45° | AST_02_3,5MM_45° | AST_452_3,5
X101 | AST_03_3,5MM | AST_03_3,5MM_45° | AST_453_3,5

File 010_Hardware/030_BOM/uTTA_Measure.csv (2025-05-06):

Part | Value | Device | Package | Description | MF | MPN | OC_FARNELL | OC_NEWARK | PACKAGE | TOLERANCE
C1 | 4.7u/25V | C-EUC0805 | C0805 | CAPACITOR, European symbol |  |  |  |  | C0805
C2 | 4.7u/25V | C-EUC0805 | C0805 | CAPACITOR, European symbol |  |  |  |  | C0805
C3 | 4.7u/25V | C-EUC0805 | C0805 | CAPACITOR, European symbol |  |  |  |  | C0805
C4 | 4.7u/25V | C-EUC0805 | C0805 | CAPACITOR, European symbol |  |  |  |  | C0805
C5 | 4.7u/25V | C-EUC0805 | C0805 | CAPACITOR, European symbol |  |  |  |  | C0805
C102.1 | 1u/25V | C-EUC0603 | C0603 | CAPACITOR, European symbol |  |  |  |  | C0603
C102.2 | 1u/25V | C-EUC0603 | C0603 | CAPACITOR, European symbol |  |  |  |  | C0603
C102.3 | 1u/25V | C-EUC0603 | C0603 | CAPACITOR, European symbol |  |  |  |  | C0603
C102.4 | 1u/25V | C-EUC0603 | C0603 | CAPACITOR, European symbol |  |  |  |  | C0603
C104.1 | 1u/25V | C-EUC0603 | C0603 | CAPACITOR, European symbol |  |  |  |  | C0603
C104.2 | 1u/25V | C-EUC0603 | C0603 | CAPACITOR, European symbol |  |  |  |  | C0603
C104.3 | 1u/25V | C-EUC0603 | C0603 | CAPACITOR, European symbol |  |  |  |  | C0603
C104.4 | 1u/25V | C-EUC0603 | C0603 | CAPACITOR, European symbol |  |  |  |  | C0603
C105.1 | 10p | C-EUC0603 | C0603 | CAPACITOR, European symbol |  |  |  |  | C0603
C105.2 | 10p | C-EUC0603 | C0603 | CAPACITOR, European symbol |  |  |  |  | C0603
C105.3 | 10p | C-EUC0603 | C0603 | CAPACITOR, European symbol |  |  |  |  | C0603
C105.4 | 10p | C-EUC0603 | C0603 | CAPACITOR, European symbol |  |  |  |  | C0603
C106.1 | 330p | C-EUC0603 | C0603 | CAPACITOR, European symbol |  |  |  |  | C0603
C106.2 | 330p | C-EUC0603 | C0603 | CAPACITOR, European symbol |  |  |  |  | C0603
C106.3 | 330p | C-EUC0603 | C0603 | CAPACITOR, European symbol |  |  |  |  | C0603
C106.4 | 330p | C-EUC0603 | C0603 | CAPACITOR, European symbol |  |  |  |  | C0603
C107.1 | DNP | C-EUC0603 | C0603 | CAPACITOR, European symbol |  |  |  |  | C0603
C107.2 | DNP | C-EUC0603 | C0603 | CAPACITOR, European symbol |  |  |  |  | C0603
C107.3 | DNP | C-EUC0603 | C0603 | CAPACITOR, European symbol |  |  |  |  | C0603
C107.4 | DNP | C-EUC0603 | C0603 | CAPACITOR, European symbol |  |  |  |  | C0603
C121 | 100n/50V | C-EUC0603 | C0603 | CAPACITOR, European symbol |  |  |  |  | C0603
C122.1 | 1u/25V | C-EUC0603 | C0603 | CAPACITOR, European symbol |  |  |  |  | C0603
C123.1 | 100n/50V | C-EUC0603 | C0603 | CAPACITOR, European symbol |  |  |  |  | C0603
C152.1 | 1u/25V | C-EUC0603 | C0603 | CAPACITOR, European symbol |  |  |  |  | C0603
C152.3 | 1u/25V | C-EUC0603 | C0603 | CAPACITOR, European symbol |  |  |  |  | C0603
C153.1 | 10n/25V | C-EUC0603 | C0603 | CAPACITOR, European symbol |  |  |  |  | C0603
C153.2 | 10n/25V | C-EUC0603 | C0603 | CAPACITOR, European symbol |  |  |  |  | C0603
C153.3 | 10n/25V | C-EUC0603 | C0603 | CAPACITOR, European symbol |  |  |  |  | C0603
C153.4 | 10n/25V | C-EUC0603 | C0603 | CAPACITOR, European symbol |  |  |  |  | C0603
C301 | 100n/50V | C-EUC0603 | C0603 | CAPACITOR, European symbol |  |  |  |  | C0603
C302 | 1u/25V | C-EUC0603 | C0603 | CAPACITOR, European symbol |  |  |  |  | C0603
C303 | 1u/25V | C-EUC0603 | C0603 | CAPACITOR, European symbol |  |  |  |  | C0603
C304 | 1u/25V | C-EUC0603 | C0603 | CAPACITOR, European symbol |  |  |  |  | C0603
C305 | 100n/50V | C-EUC0603 | C0603 | CAPACITOR, European symbol |  |  |  |  | C0603
C306 | 100n/50V | C-EUC0603 | C0603 | CAPACITOR, European symbol |  |  |  |  | C0603
C307 | 100n/50V | C-EUC0603 | C0603 | CAPACITOR, European symbol |  |  |  |  | C0603
C321.1 | 100n/50V | C-EUC0603 | C0603 | CAPACITOR, European symbol |  |  |  |  | C0603
C321.2 | 100n/50V | C-EUC0603 | C0603 | CAPACITOR, European symbol |  |  |  |  | C0603
C351.1 | 1u/25V | C-EUC0603 | C0603 | CAPACITOR, European symbol |  |  |  |  | C0603
C351.2 | 1u/25V | C-EUC0603 | C0603 | CAPACITOR, European symbol |  |  |  |  | C0603
C351.3 | 1u/25V | C-EUC0603 | C0603 | CAPACITOR, European symbol |  |  |  |  | C0603
C351.4 | 1u/25V | C-EUC0603 | C0603 | CAPACITOR, European symbol |  |  |  |  | C0603
C352.1 | 1u/25V | C-EUC0603 | C0603 | CAPACITOR, European symbol |  |  |  |  | C0603
C352.2 | 1u/25V | C-EUC0603 | C0603 | CAPACITOR, European symbol |  |  |  |  | C0603
C352.3 | 1u/25V | C-EUC0603 | C0603 | CAPACITOR, European symbol |  |  |  |  | C0603
C352.4 | 1u/25V | C-EUC0603 | C0603 | CAPACITOR, European symbol |  |  |  |  | C0603
C601.1 | 100n/50V | C-EUC0603 | C0603 | CAPACITOR, European symbol |  |  |  |  | C0603
C601.2 | 100n/50V | C-EUC0603 | C0603 | CAPACITOR, European symbol |  |  |  |  | C0603
C601.3 | 100n/50V | C-EUC0603 | C0603 | CAPACITOR, European symbol |  |  |  |  | C0603
C601.4 | 100n/50V | C-EUC0603 | C0603 | CAPACITOR, European symbol |  |  |  |  | C0603
C602.1 | 10n/50V | C-EUC0603 | C0603 | CAPACITOR, European symbol |  |  |  |  | C0603
C602.2 | 10n/50V | C-EUC0603 | C0603 | CAPACITOR, European symbol |  |  |  |  | C0603
C602.3 | 10n/50V | C-EUC0603 | C0603 | CAPACITOR, European symbol |  |  |  |  | C0603
C602.4 | 10n/50V | C-EUC0603 | C0603 | CAPACITOR, European symbol |  |  |  |  | C0603
D101.1 | SD101 | SD101AWS | SOD323-R |  |  |  |  |  | SOD-323
D101.2 | SD101 | SD101AWS | SOD323-R |  |  |  |  |  | SOD-323
D101.3 | SD101 | SD101AWS | SOD323-R |  |  |  |  |  | SOD-323
D101.4 | SD101 | SD101AWS | SOD323-R |  |  |  |  |  | SOD-323
D151 | MM3Z3V3T1GR | MM3Z3V3T1GR | SOD323-R |  |  |  |  |  | SOD323
D152 | MM3Z3V3T1GR | MM3Z3V3T1GR | SOD323-R |  |  |  |  |  | SOD323
D351.1 | SD101 | SD101AWS | SOD323-R |  |  |  |  |  | SOD-323
D351.2 | SD101 | SD101AWS | SOD323-R |  |  |  |  |  | SOD-323
D351.3 | SD101 | SD101AWS | SOD323-R |  |  |  |  |  | SOD-323
D351.4 | SD101 | SD101AWS | SOD323-R |  |  |  |  |  | SOD-323
IC101.1 | LT1167 | LT1167 | SO08 |  |  |  |  |  | SO-8
IC101.2 | LT1167 | LT1167 | SO08 |  |  |  |  |  | SO-8
IC101.3 | LT1167 | LT1167 | SO08 |  |  |  |  |  | SO-8
IC101.4 | LT1167 | LT1167 | SO08 |  |  |  |  |  | SO-8
IC151.1 | MCP602SN | MCP602SN | SO08 | Single Op Amp 2.7V to 6.0V Single Supply CMOS |  |  |  |  | SO-08
IC151.3 | MCP602SN | MCP602SN | SO08 | Single Op Amp 2.7V to 6.0V Single Supply CMOS |  |  |  |  | SO-08
IC301 | AD5664 | AD5664R | MSOP10 | D/A-Wandler 4 Kanal 16bit SPI-Interface Lieferant: RS-ComponentsArtikelnummer: 709-5960
IC302 | LT1004CLP-2.5 | LT1004CLP-2.5 | TO92- |  |  |  |  |  | TO-92
IC303 | TL074D | TL074D | SO14 | OP AMP |  |  |  |  | SO-14
IC351.1 | AD8672ARZ | OPA2156ID | SO08 |  |  |  |  |  | SO-08
IC351.2 | AD8672ARZ | OPA2156ID | SO08 |  |  |  |  |  | SO-08
IC351.3 | AD8672ARZ | OPA2156ID | SO08 |  |  |  |  |  | SO-08
IC351.4 | AD8672ARZ | OPA2156ID | SO08 |  |  |  |  |  | SO-08
IC601.1 | MAX6675ISA | MAX6675ISA | SO08 |  |  |  |  |  | SO-8
IC601.2 | MAX6675ISA | MAX6675ISA | SO08 |  |  |  |  |  | SO-8
IC601.3 | MAX6675ISA | MAX6675ISA | SO08 |  |  |  |  |  | SO-8
IC601.4 | MAX6675ISA | MAX6675ISA | SO08 |  |  |  |  |  | SO-8
JP101.1 |  | JP2QE | JP2Q | JUMPER
JP101.2 |  | JP2QE | JP2Q | JUMPER
JP101.3 |  | JP2QE | JP2Q | JUMPER
JP101.4 |  | JP2QE | JP2Q | JUMPER
L101.1 | FBMMZ2012S | FBMMZ2012S | FB2012 | FERRITE BEAD |  |  |  |  | 2012
L101.2 | FBMMZ2012S | FBMMZ2012S | FB2012 | FERRITE BEAD |  |  |  |  | 2012
L101.3 | FBMMZ2012S | FBMMZ2012S | FB2012 | FERRITE BEAD |  |  |  |  | 2012
L101.4 | FBMMZ2012S | FBMMZ2012S | FB2012 | FERRITE BEAD |  |  |  |  | 2012
L102.1 | FBMMZ2012S | FBMMZ2012S | FB2012 | FERRITE BEAD |  |  |  |  | 2012
L102.2 | FBMMZ2012S | FBMMZ2012S | FB2012 | FERRITE BEAD |  |  |  |  | 2012
L102.3 | FBMMZ2012S | FBMMZ2012S | FB2012 | FERRITE BEAD |  |  |  |  | 2012
L102.4 | FBMMZ2012S | FBMMZ2012S | FB2012 | FERRITE BEAD |  |  |  |  | 2012
L121 | FBMMZ2012S | FBMMZ2012S | FB2012 | FERRITE BEAD |  |  |  |  | 2012
L301 | FBMMZ2012S | FBMMZ2012S | FB2012 | FERRITE BEAD |  |  |  |  | 2012
L601.1 | FBMMZ2012S | FBMMZ2012S | FB2012 | FERRITE BEAD |  |  |  |  | 2012
L601.2 | FBMMZ2012S | FBMMZ2012S | FB2012 | FERRITE BEAD |  |  |  |  | 2012
L601.3 | FBMMZ2012S | FBMMZ2012S | FB2012 | FERRITE BEAD |  |  |  |  | 2012
L601.4 | FBMMZ2012S | FBMMZ2012S | FB2012 | FERRITE BEAD |  |  |  |  | 2012
L602.1 | FBMMZ2012S | FBMMZ2012S | FB2012 | FERRITE BEAD |  |  |  |  | 2012
L602.2 | FBMMZ2012S | FBMMZ2012S | FB2012 | FERRITE BEAD |  |  |  |  | 2012
L602.3 | FBMMZ2012S | FBMMZ2012S | FB2012 | FERRITE BEAD |  |  |  |  | 2012
L602.4 | FBMMZ2012S | FBMMZ2012S | FB2012 | FERRITE BEAD |  |  |  |  | 2012
LED1 | GREEN | LEDSML0805 | SML0805 | LED
LED2 | RED | LEDSML0805 | SML0805 | LED
LED3 | GREEN | LEDSML0805 | SML0805 | LED
R1 | 680 | R-EU_R0603 | R0603 | RESISTOR, European symbol |  |  |  |  | R0603
R2 | 680 | R-EU_R0603 | R0603 | RESISTOR, European symbol |  |  |  |  | R0603
R3 | 680 | R-EU_R0603 | R0603 | RESISTOR, European symbol |  |  |  |  | R0603
R4 | 0R | R-EU_R0603 | R0603 | RESISTOR, European symbol |  |  |  |  | R0603
R5 | DNP | R-EU_R0603 | R0603 | RESISTOR, European symbol |  |  |  |  | R0603
R101.1 | 49k9 | R-EU_R0805 | R0805 | RESISTOR, European symbol |  |  |  |  | R0805 | 0.1%
R101.2 | 49k9 | R-EU_R0805 | R0805 | RESISTOR, European symbol |  |  |  |  | R0805 | 0.1%
R101.3 | 49k9 | R-EU_R0805 | R0805 | RESISTOR, European symbol |  |  |  |  | R0805 | 0.1%
R101.4 | 49k9 | R-EU_R0805 | R0805 | RESISTOR, European symbol |  |  |  |  | R0805 | 0.1%
R102.1 | 1k | R-EU_R0603 | R0603 | RESISTOR, European symbol |  |  |  |  | R0603
R102.2 | 1k | R-EU_R0603 | R0603 | RESISTOR, European symbol |  |  |  |  | R0603
R102.3 | 1k | R-EU_R0603 | R0603 | RESISTOR, European symbol |  |  |  |  | R0603
R102.4 | 1k | R-EU_R0603 | R0603 | RESISTOR, European symbol |  |  |  |  | R0603
R103.1 | 0R | R-EU_R0603 | R0603 | RESISTOR, European symbol |  |  |  |  | R0603
R103.2 | 0R | R-EU_R0603 | R0603 | RESISTOR, European symbol |  |  |  |  | R0603
R103.3 | 0R | R-EU_R0603 | R0603 | RESISTOR, European symbol |  |  |  |  | R0603
R103.4 | 0R | R-EU_R0603 | R0603 | RESISTOR, European symbol |  |  |  |  | R0603
R121.1 | 10k | R-EU_R0603 | R0603 | RESISTOR, European symbol |  |  |  |  | R0603
R151.1 | 24k9 | R-EU_R0603 | R0603 | RESISTOR, European symbol |  |  |  |  | R0603 | 0.1%
R151.2 | 24k9 | R-EU_R0603 | R0603 | RESISTOR, European symbol |  |  |  |  | R0603 | 0.1%
R151.3 | 24k9 | R-EU_R0603 | R0603 | RESISTOR, European symbol |  |  |  |  | R0603 | 0.1%
R151.4 | 24k9 | R-EU_R0603 | R0603 | RESISTOR, European symbol |  |  |  |  | R0603 | 0.1%
R152.2 | 10k | R-EU_R0603 | R0603 | RESISTOR, European symbol |  |  |  |  | R0603 | 0.1%
R152.3 | 10k | R-EU_R0603 | R0603 | RESISTOR, European symbol |  |  |  |  | R0603 | 0.1%
R152.4 | 10k | R-EU_R0603 | R0603 | RESISTOR, European symbol |  |  |  |  | R0603 | 0.1%
R153.1 | 120 | R-EU_R0603 | R0603 | RESISTOR, European symbol |  |  |  |  | R0603
R153.2 | 120 | R-EU_R0603 | R0603 | RESISTOR, European symbol |  |  |  |  | R0603
R153.3 | 120 | R-EU_R0603 | R0603 | RESISTOR, European symbol |  |  |  |  | R0603
R153.4 | 120 | R-EU_R0603 | R0603 | RESISTOR, European symbol |  |  |  |  | R0603
R154A | 100k | R-EU_R0603 | R0603 | RESISTOR, European symbol |  |  |  |  | R0603 | 0.1%
R154B | 100k | R-EU_R0603 | R0603 | RESISTOR, European symbol |  |  |  |  | R0603 | 0.1%
R155A | 15K | R-EU_R0603 | R0603 | RESISTOR, European symbol |  |  |  |  | R0603 | 0.1%
R156B | DNP | R-EU_R0603 | R0603 | RESISTOR, European symbol |  |  |  |  | R0603
R157 | 4k7 | R-EU_R0603 | R0603 | RESISTOR, European symbol |  |  |  |  | R0603
R158 | 100k | R-EU_R0603 | R0603 | RESISTOR, European symbol |  |  |  |  | R0603
R159 | 4k7 | R-EU_R0603 | R0603 | RESISTOR, European symbol |  |  |  |  | R0603
R160 | 100k | R-EU_R0603 | R0603 | RESISTOR, European symbol |  |  |  |  | R0603
R301 | 10k | R-EU_R0603 | R0603 | RESISTOR, European symbol |  |  |  |  | R0603
R302 | 1k | R-EU_R0603 | R0603 | RESISTOR, European symbol |  |  |  |  | R0603
R303 | 1k | R-EU_R0603 | R0603 | RESISTOR, European symbol |  |  |  |  | R0603
R306 | DNP | R-EU_R0603 | R0603 | RESISTOR, European symbol |  |  |  |  | R0603
R321.1 | 10k | R-EU_R0603 | R0603 | RESISTOR, European symbol |  |  |  |  | R0603 | 0.1%
R321.2 | 10k | R-EU_R0603 | R0603 | RESISTOR, European symbol |  |  |  |  | R0603 | 0.1%
R322.1 | 1k | R-EU_R0603 | R0603 | RESISTOR, European symbol |  |  |  |  | R0603
R322.2 | 1k | R-EU_R0603 | R0603 | RESISTOR, European symbol |  |  |  |  | R0603
R326.1 | 4k99 | R-EU_R0603 | R0603 | RESISTOR, European symbol |  |  |  |  | R0603 | 0.1%
R326.2 | 4k99 | R-EU_R0603 | R0603 | RESISTOR, European symbol |  |  |  |  | R0603 | 0.1%
R351.1 | 10k | R-EU_R0603 | R0603 | RESISTOR, European symbol |  |  |  |  | R0603 | 0.1%
R351.2 | 10k | R-EU_R0603 | R0603 | RESISTOR, European symbol |  |  |  |  | R0603 | 0.1%
R351.3 | 10k | R-EU_R0603 | R0603 | RESISTOR, European symbol |  |  |  |  | R0603 | 0.1%
R351.4 | 10k | R-EU_R0603 | R0603 | RESISTOR, European symbol |  |  |  |  | R0603 | 0.1%
R352.1 | 1k | R-EU_R0603 | R0603 | RESISTOR, European symbol |  |  |  |  | R0603 | 0.1%
R352.2 | 1k | R-EU_R0603 | R0603 | RESISTOR, European symbol |  |  |  |  | R0603 | 0.1%
R352.3 | 1k | R-EU_R0603 | R0603 | RESISTOR, European symbol |  |  |  |  | R0603 | 0.1%
R352.4 | 1k | R-EU_R0603 | R0603 | RESISTOR, European symbol |  |  |  |  | R0603 | 0.1%
R353.1 | 10k | R-EU_R0603 | R0603 | RESISTOR, European symbol |  |  |  |  | R0603 | 0.1%
R353.2 | 10k | R-EU_R0603 | R0603 | RESISTOR, European symbol |  |  |  |  | R0603 | 0.1%
R353.3 | 10k | R-EU_R0603 | R0603 | RESISTOR, European symbol |  |  |  |  | R0603 | 0.1%
R353.4 | 10k | R-EU_R0603 | R0603 | RESISTOR, European symbol |  |  |  |  | R0603 | 0.1%
R354.1 | 1k | R-EU_R0603 | R0603 | RESISTOR, European symbol |  |  |  |  | R0603 | 0.1%
R354.2 | 1k | R-EU_R0603 | R0603 | RESISTOR, European symbol |  |  |  |  | R0603 | 0.1%
R354.3 | 1k | R-EU_R0603 | R0603 | RESISTOR, European symbol |  |  |  |  | R0603 | 0.1%
R354.4 | 1k | R-EU_R0603 | R0603 | RESISTOR, European symbol |  |  |  |  | R0603 | 0.1%
R355.1 | 22R | R-EU_R0805 | R0805 | RESISTOR, European symbol |  |  |  |  | R0805 | 0.1%
R355.2 | 22R | R-EU_R0805 | R0805 | RESISTOR, European symbol |  |  |  |  | R0805 | 0.1%
R355.3 | 22R | R-EU_R0805 | R0805 | RESISTOR, European symbol |  |  |  |  | R0805 | 0.1%
R355.4 | 22R | R-EU_R0805 | R0805 | RESISTOR, European symbol |  |  |  |  | R0805 | 0.1%
R601.1 | 10k | R-EU_R0603 | R0603 | RESISTOR, European symbol |  |  |  |  | R0603
R601.2 | 10k | R-EU_R0603 | R0603 | RESISTOR, European symbol |  |  |  |  | R0603
R601.3 | 10k | R-EU_R0603 | R0603 | RESISTOR, European symbol |  |  |  |  | R0603
R601.4 | 10k | R-EU_R0603 | R0603 | RESISTOR, European symbol |  |  |  |  | R0603
S1 |  | 10-XX | B3F-10XX | OMRON SWITCH |  | B3F-1000 | 176432 | 36M3542
S11 |  | 10-XX | B3F-10XX | OMRON SWITCH |  | B3F-1000 | 176432 | 36M3542
S351.2 | SS_ESP101 | SS_ESP101 | SS_ESP101
S351.3 | SS_ESP101 | SS_ESP101 | SS_ESP101
S351.4 | SS_ESP101 | SS_ESP101 | SS_ESP101
T151 | BSS138PS | BSS138PS | SOT363_PHILIPS | BSS138PS Dual N-CH MOSFET 60V, 320mA, 280mW, SOT363 |  |  |  |  | SOT-363
TP1 | TPC90 | TPC90 | C90
TP3 | TPC90H30 | TPC90H30 | C90H30
TP4 | TPC90H30 | TPC90H30 | C90H30
TP5 | TPC90H30 | TPC90H30 | C90H30
TP6 | TPC90H30 | TPC90H30 | C90H30
TP7 | TPC90H30 | TPC90H30 | C90H30
TP8 | TPC90H30 | TPC90H30 | C90H30
TP9 | TPC90H30 | TPC90H30 | C90H30
TP10 | TPC90H30 | TPC90H30 | C90H30
TP11 | TPC90H30 | TPC90H30 | C90H30
TP12 | TPC90H30 | TPC90H30 | C90H30
TP17 | TPC90H30 | TPC90H30 | C90H30
TP18 | TPC90H30 | TPC90H30 | C90H30
TP19 | TPC90H30 | TPC90H30 | C90H30
TP20 | TPC90H30 | TPC90H30 | C90H30
TP21 | TPC90H30 | TPC90H30 | C90H30
TP22 | TPC90H30 | TPC90H30 | C90H30
TP23 | TPC90H30 | TPC90H30 | C90H30
TP24 | TPC90H30 | TPC90H30 | C90H30
TP103.1 | TPC90 | TPC90 | C90
TP103.2 | TPC90 | TPC90 | C90
TP103.3 | TPC90 | TPC90 | C90
TP103.4 | TPC90 | TPC90 | C90
TP104.1 | TPC90 | TPC90 | C90
TP104.2 | TPC90 | TPC90 | C90
TP104.3 | TPC90 | TPC90 | C90
TP104.4 | TPC90 | TPC90 | C90
TP105.1 | TPC90 | TPC90 | C90
TP105.2 | TPC90 | TPC90 | C90
TP105.3 | TPC90 | TPC90 | C90
TP105.4 | TPC90 | TPC90 | C90
TP106.1 | TPC90H30 | TPC90H30 | C90H30
TP106.2 | TPC90H30 | TPC90H30 | C90H30
TP106.3 | TPC90H30 | TPC90H30 | C90H30
TP106.4 | TPC90H30 | TPC90H30 | C90H30
TP107.1 | TPC90 | TPC90 | C90
TP107.2 | TPC90 | TPC90 | C90
TP107.3 | TPC90 | TPC90 | C90
TP107.4 | TPC90 | TPC90 | C90
TP151.1 | TPC90H30 | TPC90H30 | C90H30
TP151.2 | TPC90H30 | TPC90H30 | C90H30
TP151.3 | TPC90H30 | TPC90H30 | C90H30
TP151.4 | TPC90H30 | TPC90H30 | C90H30
TP152.1 | TPC90 | TPC90 | C90
TP152.2 | TPC90 | TPC90 | C90
TP152.3 | TPC90H30 | TPC90H30 | C90H30
TP152.4 | TPC90H30 | TPC90H30 | C90H30
TP153 | TPC90 | TPC90 | C90
TP153.1 | TPC90H30 | TPC90H30 | C90H30
TP153.2 | TPC90H30 | TPC90H30 | C90H30
TP153.3 | TPC90H30 | TPC90H30 | C90H30
TP153.4 | TPC90H30 | TPC90H30 | C90H30
TP154 | TPC90 | TPC90 | C90
TP301 | TPC90 | TPC90 | C90
TP302 | TPC90 | TPC90 | C90
TP303 | TPC90H30 | TPC90H30 | C90H30
TP304 | TPC90 | TPC90 | C90
TP305 | TPC90H30 | TPC90H30 | C90H30
TP306 | TPC90 | TPC90 | C90
TP321.1 | TPC90 | TPC90 | C90
TP321.2 | TPC90 | TPC90 | C90
TP322.1 | TPC90 | TPC90 | C90
TP322.2 | TPC90 | TPC90 | C90
TP351.1 | TPC90 | TPC90 | C90
TP351.2 | TPC90 | TPC90 | C90
TP351.3 | TPC90 | TPC90 | C90
TP351.4 | TPC90 | TPC90 | C90
TP352.1 | TPC90 | TPC90 | C90
TP352.2 | TPC90 | TPC90 | C90
TP352.3 | TPC90 | TPC90 | C90
TP352.4 | TPC90 | TPC90 | C90
TP353.1 | TPC90 | TPC90 | C90
TP353.2 | TPC90 | TPC90 | C90
TP353.3 | TPC90 | TPC90 | C90
TP353.4 | TPC90 | TPC90 | C90
TP354.2 | TPC90 | TPC90 | C90
TP354.3 | TPC90 | TPC90 | C90
TP354.4 | TPC90 | TPC90 | C90
TP355.1 | TPC90 | TPC90 | C90
TP355.2 | TPC90 | TPC90 | C90
TP355.3 | TPC90 | TPC90 | C90
TP355.4 | TPC90 | TPC90 | C90
TP9354.1 | TPC90 | TPC90 | C90
U11 | NUCLEO_F103_BOT | NUCLEO_F103_BOT | NUCLEO_BRD64_LOWER
U121.1 | W25Q128JV | W25Q80BVSSIG | SO08W
X101.1 | BU-SMA-GSPECIAL | BU-SMA-GSPECIAL | BU_SMA_3P | FEMALE SMA CONNECTOR
X101.2 | BU-SMA-GSPECIAL | BU-SMA-GSPECIAL | BU_SMA_3P | FEMALE SMA CONNECTOR
X101.3 | BU-SMA-GSPECIAL | BU-SMA-GSPECIAL | BU_SMA_3P | FEMALE SMA CONNECTOR
X101.4 | BU-SMA-GSPECIAL | BU-SMA-GSPECIAL | BU_SMA_3P | FEMALE SMA CONNECTOR
X601 |  | MPT4 | 4POL254 | PHOENIX CONNECTOR
X602 |  | MPT4 | 4POL254 | PHOENIX CONNECTOR

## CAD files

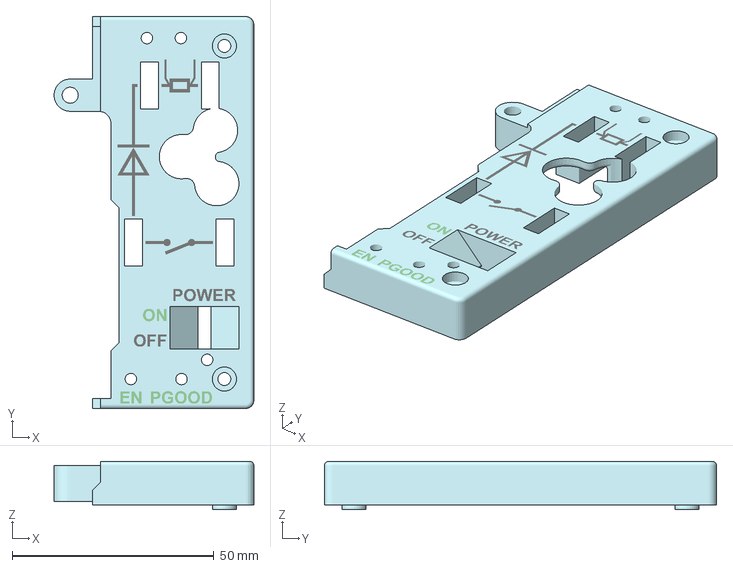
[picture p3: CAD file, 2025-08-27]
010_Hardware/060_Mechanics/Lower_Lid.3mf
49.5 x 97.1 x 11.9 mm

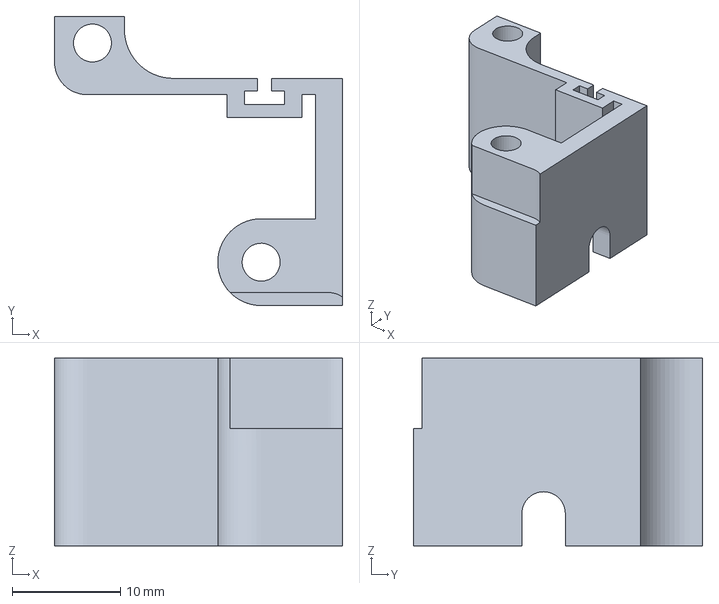
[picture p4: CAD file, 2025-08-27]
010_Hardware/060_Mechanics/Sliding_Wall.3mf
26.6 x 26.7 x 17.3 mm

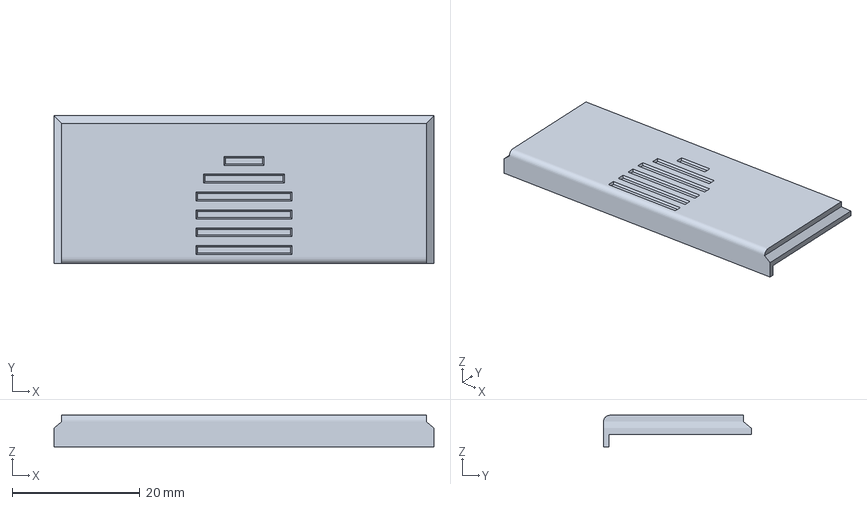
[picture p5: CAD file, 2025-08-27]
010_Hardware/060_Mechanics/Battery_Lid.3mf
59.5 x 23.2 x 4.95 mm

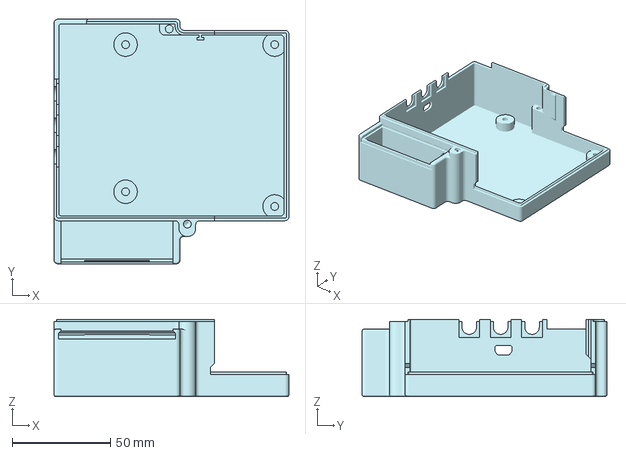
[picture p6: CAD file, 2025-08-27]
010_Hardware/060_Mechanics/Baseplate.3mf
119.8 x 124.8 x 39.5 mm

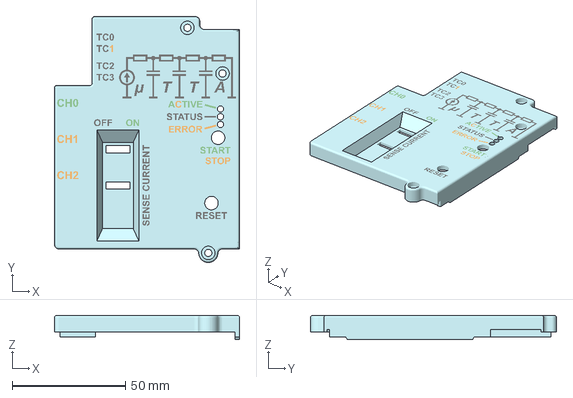
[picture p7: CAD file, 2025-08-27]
010_Hardware/060_Mechanics/Upper_Lid.3mf
81.8 x 108.8 x 10.8 mm

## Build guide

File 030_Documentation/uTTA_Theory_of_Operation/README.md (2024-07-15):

# Theory of Operation


## Pre-Heating Phase
The whole measurement starts with a so-called pre-heating phase. The pre-heating phase is intended to measure the initial voltage drops of the junctions under test (JUT). This is needed to be able to judge after the measurement if the JUTs have cooled completely to thermal equilibrium. During the pre-heating phase the sample rate on all channels is reduced to its lowest setting, which is a sampling period of 65536µs or ~15.26 Samples/s. Furthermore, the programmable gain stage of the driven JUT is set to its initial setting (higher gain).

## Heating Phase
In the heating phase the uTTA switches on the heating current switch to enable external power supply which provides the heating current for the DUT. In theory you should be able to use any power supply with current limit you have on hand. Output voltage requirements may depend a little on your specific setup. My setup always worked at ~3V with a heating current of ~10-12A, whereby the wires between uTTA and DUT were almost 2 meters long. In the heating phase uTTA switches the PGA into the preset setting (typically lower gain) to be able to measure the diode voltage while the heating current is running through the JUT. The diode voltage at the end of the heating phase is important to be able to calculate the dissipated power in the JUT. During the whole phase the sampling rate is still at its lowest setting because the data during heating do not provide much valuable content. At the end of the heating phase uTTA does multiple things in very short succession.
1. Switch the PGA back to its higher gain setting to have the full measure range during the coming cooling phase
2. Set the ADC sampling rate to maximum speed. This means a sample rate of 2MS/s per channel. The samples are taken simultaneously on all 4 channels (because the STM32 has 4 built in ADCs).
3. Switch off the heating current switch and cut off the heating current.

## Cooling Phase

With these settings done the heating current through the device is cut really fast (~1-2µs) and all the inductive energy is dissipated in the Freewheeling network in parallel to the JUT (on the uTTA power PCB). While the current is freewheeling, the microcontroller is continuously sampling at 2MS/s. After 250 samples the ADC halves its sampling rate to 1MS/s, and after another 250Samples to 500kS/s. This process of taking 250samples and reducing the sample rate is done until the minimum sample rate of ~15.26 Samples/s is reached. From there the sampling continues until the preset measurement time is reached. As the correct timing is extremely crucial to the whole process the sampling is controlled by an internal timer which is set to these sampling rates. The change of sampling rates is performed by the timers’ preload registers which are automatically reloaded as soon as 250 samples were generated.

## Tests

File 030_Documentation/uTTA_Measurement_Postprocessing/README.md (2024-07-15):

# Measurement postprocessing
## Measurement data retrieval

All measurement values of the ADC are transferred via DMA into a circular buffer array with a length of 5000 samples. From there the values are taken in blocks of 250 samples, transformed into a human readable format and transferred into the flash memory. As soon as the measurement is completed the user can transfer these measurement data files onto the PC via the serial port. For this purpose a LabView GUI was built to ease up the transfer process. After the transfer you will get a measurement file with the file extension *.t3r. This file extension was borrowed from the T3STER system, but is __NOT__ compatible with any of these systems.



## The measurement data file

As said before the measurement file has a *.t3r file extension to give it a unique name. Nevertheless, this is still just a plain text file you can open with any text editor.

### File Header

Each measurement file starts with a file header which includes general information and settings which are needed for the postprocessing. All values are separated by a semicolon (the German delimiter for CSV-files).



#### File Version
  The first line always indicates the file version. At the moment this should be version 2.2. Earlier file versions contained less information

#### CH_ Name
The following three lines always define a set of parameters for the measurement channels:
+ The symbolic name of the channel. This is intended to ease up the postprocessing process. Especially when you do a lot of measurements.
+ $JUT_{Offset}$: The offset voltage of the diode voltage to temperature conversion line in µV. This value is not used by anything and can therefore be set to 0. The postprocessing function simply does a difference temperature measurement, therefore an accurate offset is not needed.
+ $JUT_{LinearGain}$: The linear portion of the voltage to temperature conversion slope in µV/K.
+ $JUT_{QuadraticGain}$:The quadratic portion of the voltage to temperature conversion slow in µV/K<sup>2</sup>. This value is currently not used and can therefore be set to 0.

For conversion of the measured voltage to a temperature the postprocessing function does the following calculation: $\frac{U_{JUT.cold} + JUT_{Offset}}{JUT_{LinearGain}}$

#### StartTime
Contains the start time of the measurement. Sometimes it's helpful to know when you started your measurement (especially when you're debugging).

#### StartDate
The date when the measurement was performed in DD.MM.YYYY format.

#### T<sub>samp,fast</sub>
Is the setting of the fast sample rate which is used at the start of the cooling section. This cryptic value can be converted to Samples per second with the following formula:
$\frac{8 MHz}{T_{samp,fast}}$

#### T<sub>samp,low</sub>
Is the setting of the lowest sample rate which is used most of the measurement time. This cryptic value can be converted to Samples per second with the following formula:
$\frac{8 MHz}{T_{samp,low}}$

#### Samples/Decade ($N_{SamplesDecade}$)
The name might be a bit misleading. It is not a decade but the length of a sampling block. The name is a historical choice I didn't bother to change.

#### Max. Divider
Is a slightly redundant value to T<sub>samp,low</sub>. This value basically describe how many times the sample time is halved at the beginning of the cooling section. Therefore T<sub>samp,low</sub> can be calculated from T<sub>samp,fast</sub> with the following formula:
$T_{samp,low} = T_{samp,fast} * 2^{MaxDivider}$

#### T_Preheat
This value represents the preheating time used for the measurement in seconds. Please note that this value might not be precisely reflected in the measurement as the internal state machine switched only at the beginning of a new block. Therefore a skew between the setting and the real measurement of $T_{samp.low}*N_{SamplesDecade}$ might occur.

#### T_Heat
This value represents the heating time used for the measurement in seconds. Please note that this value might not be precisely reflected in the measurement as the internal state machine switched only at the beginning of a new block. Therefore a skew between the setting and the real measurement of $T_{samp.low}*N_{SamplesDecade}$ might occur.

#### T_Cool
This value represents the cooling time used for the measurement in seconds. Please note that this value might not be precisely reflected in the measurement as the internal state machine switched only at the beginning of a new block. Therefore a skew between the setting and the real measurement of $T_{samp.low}*N_{SamplesDecade}$ might occur.

#### ADC1;ADC2;ADC3;ADC4
This is the final line of the file header. After this line the measurement data block starts.
### Measurement Data



#### #T lines
Lines starting with #T indicate a measurement data set from the type K thermocouples. After this prefix there are 4 values reflecting the 4 type K thermocouples. The values given are in tens of degrees Celsius, thus you need to divide this value by 10.

#### #B lines
Lines starting with #B indicate the start of a new block. After this prefix there is the block number which is continuously counted up to the end of the measurement. In theory you don't need this tag because with complete data (without data loss) there shouldn't be the need for it. In practice these lines have proven useful while debugging, therefore I kept them in.

#### #P lines
Lines starting with #P indicated the current gain configuration of the programmable gain amplifier. This is needed for the postprocessing to know which calibration factors need to be applied to channel 1.

#### Lines with raw numbers
All lines with raw numbers are raw ADC measurement values. The measurement values are not scaled within the measurement system, this is done at the postprocessing stage.

### File Footer



#### Cooling Start Block
This line is a helping line for the postprocessing software. As the exact number of blocks from start of the measurement to the start of the cooling phase might vary due to aforementioned timing inaccuracies an indicator was needed to find the first block of the cooling section more easily.

#### Total Blocks
This value reflects the total number of blocks generated during the measurement. 

# Measurement data postprocessing
## Conversion from measurement data to Z<sub>th</sub>-Curves
Postprocessing of the measurements is done in Python (but there is also a very crusty LabVIEW GUI if someone likes :P ). 
Currently there is no nice Python GUI. It's just a little script which creates a figure via matplotlib. 
By running the file "uTTA_Postprocess_Measurement.py" you will get these plots.



### What do you see in these plots?
+ Let's start at the top left. This plot shows the change of the JUT voltages over the whole measurement period. As previously described the heated JUT jumps to a significantly higher voltage during heating, due to the high heating current.
+ Right to the JUT voltages you can see the measured heating current. This graph has little information content. It's just there to verify nothing mysterious happened during the measurement.
+ In the second line you can see the same measurement data as above, whereas the preheating and heating section were cut off. The JUT voltages show the electrical transient which is created by the junction capacitance and the wire inductance. The heating current should ideally go to zero, but it seems like we can observe the cooling of the differential amplifier in this graph.
+ The third row on the left depicts the converted temperatures from the JUT scaling factors. The curve of the heated JUT is extended further to the switch off by using the interpolation formula. For the other two channels this is currently not implemented.
+ Third row on the right shows the measured values of the thermocouples. At the moment this plot is not scaled to the same time base as the rest of the measurement data.
+ Last row on the least depicts the calculated thermal impedance curve. You can clearly see where the interpolation curve ends and where real measurement start.
+ Last row on the right shows the coupling impedances between the heated JUT and the monitored JUTs.

In addition to the figure two files are created. The first one is a text file with all the scaled diode voltages of the whole cooling section.
The second file has the extension *.t3i (Don't ask, I forgot why). This file contains intermediate results which can be used by the "uTTA_FFT_Deconvolution.py" script for further processing.

## Conversion from Z<sub>th</sub>-Curves to time constant spectra
Here the real drama begins. In principle all the aforementioned documents contain the methods how to obtain the time constant spectrum, but all of them lack a few details which are vital for the correct function. 
In the following chapter I will try to give a summary of the process which is implemented right now. All steps are also descibed in [THERMINIC 20005 Tutorial, page 58.ff](https://therminic.org/therminic2005/APoppe_Tutorial.pdf), but some important details are missing.

1. After importing the *.t3i file the data is split into the timebase and the 3 calculated Zth curves and in the following steps only the Zth curve of the heated JUT is processed, all other channels are ignored for the moment. The imported measurement data still have the same sampling scheme as the original measurement data, therefore they are not evenly spaced (only within the blocks of 250 samples), but this is not dramatic as you will see in the next steps
2. As described the timebase needs to be logarithmic for the follwing steps. Therefore the imported timebase is converted with $z=ln(t)$. Nevertheless, this step has basically no fruitful impact, because the already unevenly spaced samples are now even more uneven.
3. To get the unevenly spaced samples into a format which can be processed later on, the samples need to be layed out on the logarithmic time axis with an even spacing. This is done by creating a new linear timebase with evenly spaced samples. The range of this timebase is $[min(z), max(z)]$ (I will call this axis the z-axis).
4. Now the unevenly spaced samples and its corresponding timebase can be interpolated to new samples onto the z-axis.
5. With this interpolated curve the derivative of the signal is calculated. This step will amplify the noise in the measurement drastically. 
6. After the derivation the curve curve needs to be modified for the FFT later on. Zero padding need to be added to the curve. This is necessary because the FFT always assumes a repetitve input signal. The signal isn't repetitve therefore, it needs to add the same amount of samples as zeros to the signal.
7. Before the deconvolution can be started two addtional curves need to be created.
   1. The weighing function $w_z(z)=e^{z-e^z}$
   2. The filter function $\frac{1}{e^{|\frac{|\Phi|-\Phi_0}{\rho}|}+1}$ (This is not mentioned in the THERMINIC Tutorial but here: [](https://diglib.tugraz.at/download.php?id=5cc8223dd3723&location=browse)

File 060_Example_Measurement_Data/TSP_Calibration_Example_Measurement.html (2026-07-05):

# µTTA Measurement Report

1. TSP Calibration Measurement

1.1. TSP Voltages

1.2. Thermocouples

1.3. Detected Temperature Steps

Step Temp | CH0 Avg. | CH1 Avg. | CH2 Avg. | Temp Avg. | Start | End
21.68 °C | 589.7 mV | 202.7 mV | 202.2 mV | 21.68 °C | 739 | 799
21.69 °C | 589.4 mV | 202.6 mV | 202.2 mV | 21.69 °C | 989 | 1049
21.88 °C | 589.4 mV | 202.7 mV | 202.2 mV | 21.88 °C | 1239 | 1299
41.72 °C | 546.9 mV | 202.8 mV | 202.3 mV | 41.72 °C | 3393 | 3453
62.33 °C | 503.7 mV | 202.8 mV | 202.3 mV | 62.33 °C | 5567 | 5627
83.06 °C | 459.9 mV | 202.8 mV | 202.3 mV | 83.06 °C | 7633 | 7693

Copy as CSV

2. Details for Channel: U21

2.1. Calibration Summary

Channel-ID: U21

Parameter | Value
Offset | 635.3995 mV
Linear Gain | -2.1134 mV/K
Quadratic Gain | 0.0000 mV²/K
Coefficient of determination | 1.0000

Copy as CSV

2.2. Temperature Interpolation Plot

3. Measurement Information

3.1 Setup Information

Parameter | Value
Device Name | WK, SN001
File Version | 3.5
Sense Current | 10.000 mA

Copy as CSV

3.2 Timing Information

Parameter | Value
Start Date | 03.05.2025
Start Time | 12:35:17
PreHeating Time | 10800 s
Heating Time | 0 s
Cooling Time | 5400 s

Copy as CSV

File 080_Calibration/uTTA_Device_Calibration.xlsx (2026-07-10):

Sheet: Initial Instructions
1. | Delete the existing calibration file from the device to be calibrated. Use the MEM:DEL Cali.cal command
2. | Reset the device by typing *RST
3. | Set the device to test mode by using the command: SYST:MODE TEST

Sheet: Instruction ISENSE
1. | Enable all 3 Sense Enable switches
2. | Connect an Amperemeter between JP101.1 Pin 4 (Positive) and JP101.1 Pin 3 (Negative)
3. | Set the sense current on the device by using the command MEAS:SET ISEN,0,xxxx. Replace xxxx with a number between 0 and 65535.
4. | Take a reading of the Amperemeter and enter the set value and the meter reading into the table in worksheet "ISENSE_CAL"
5. | Repeat the steps 3&4 for other sense current settings until you have a decent amount of values. This also serves as a check for sufficient linearity of the device.
6. | Repeat the steps 1-5 for the remaining two channels. Connect the meter to the respective headers. The pinout of the headers can be seen in the picture on the right side.
7. | Disconnect the Amperemeter and disable all Sense Enable Switches
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

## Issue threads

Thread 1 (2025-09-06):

Measurement file corrupted on repeated measurements

wtronics, 2025-09-06:
When doing repeated measurements in one test session without resetting or disconnecting the device, the measurement files of all subsequent measurements are corrupted.

## In Detail:
When repeating or doing multiple measurements on the uTTA Hardware without doing a reset the measurement file will have at least one data block where a number of samples is missing. This leads to a problem during postprocessing of the measurement which is caused by the unequal length between the timebase array and the measurement data array.

## Short term solution:

- Reset the device between each measurement. This can be accomplished by either pressing the reset button or by doing a disconnect / connect cycle in the GUI (does an automatic reset when connecting to the device).
- Added a block length check to uTTA_data_import.py to detect blocks with missing samples.

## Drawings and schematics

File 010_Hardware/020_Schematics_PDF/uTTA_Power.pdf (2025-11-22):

A

A

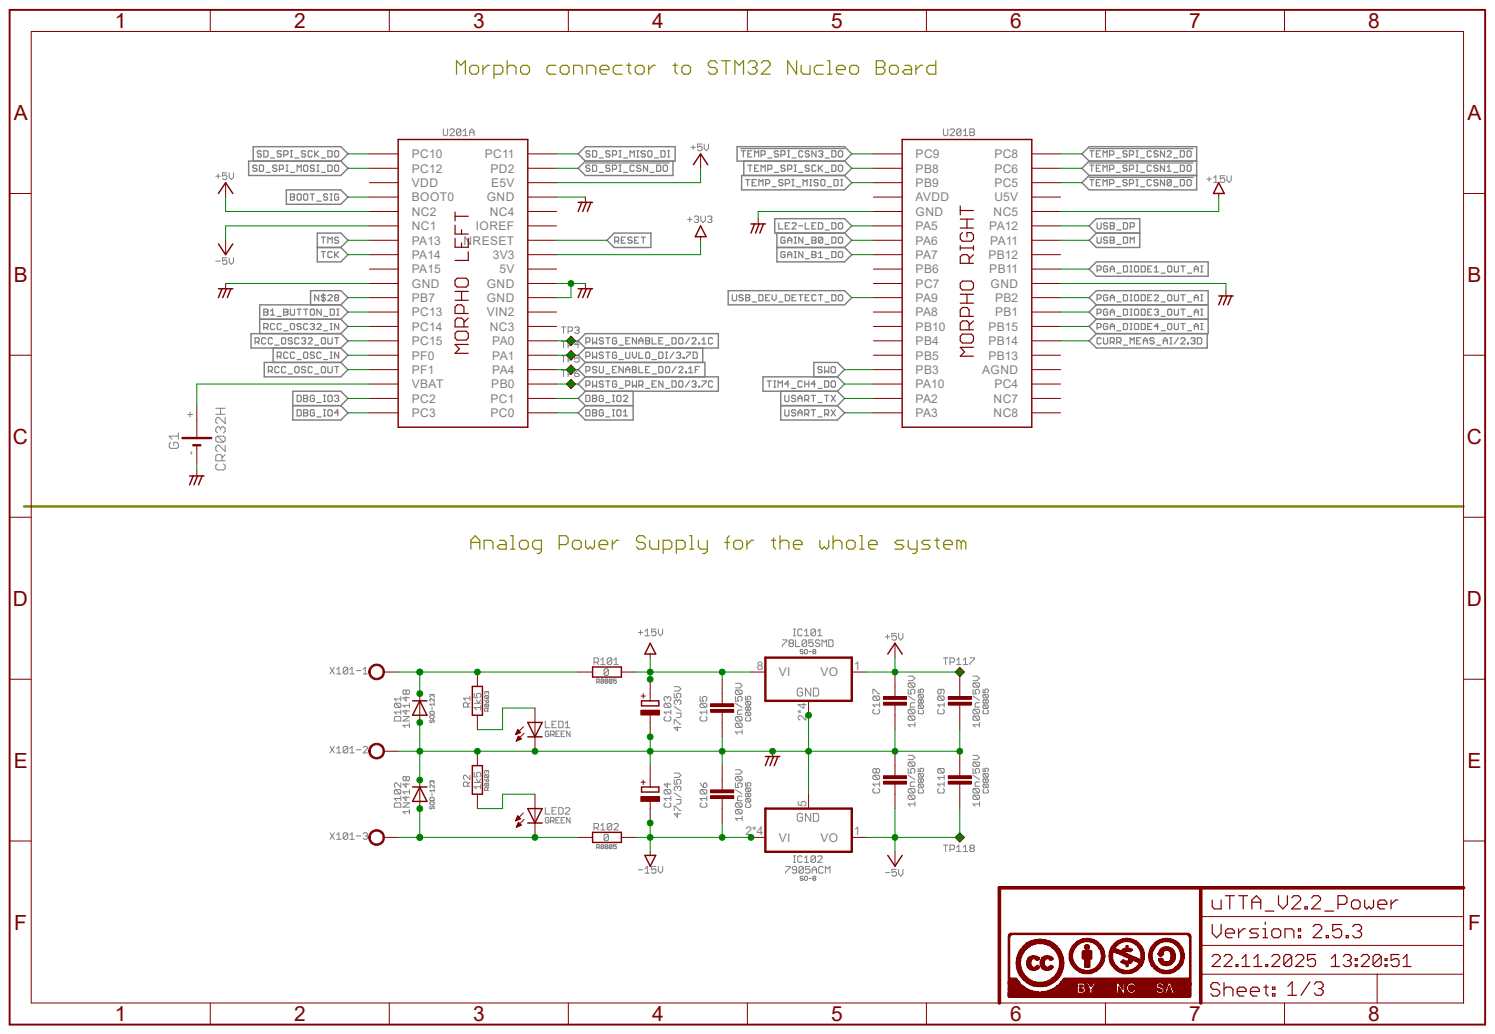
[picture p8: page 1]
BOOT0; VDD; GND; VIN2; VBAT; NRESET; IOREF; E5V GND; AVDD GND; PB11 GND; AGND

A

A

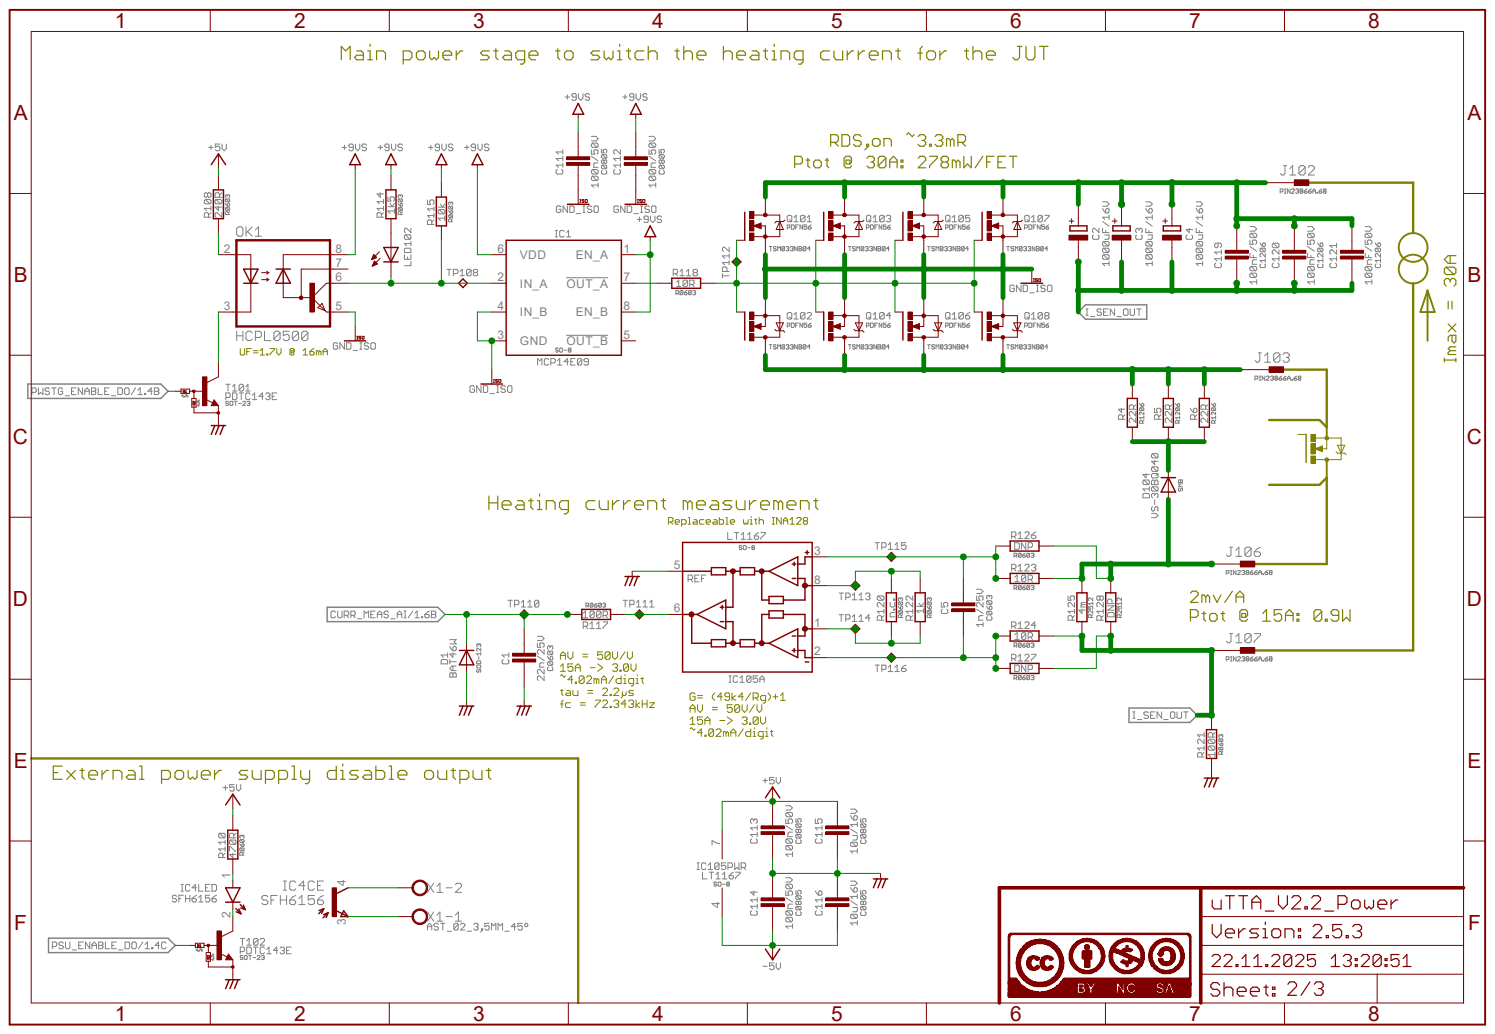
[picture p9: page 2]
GND; VDD; OUT_A; OUT_B

A

A

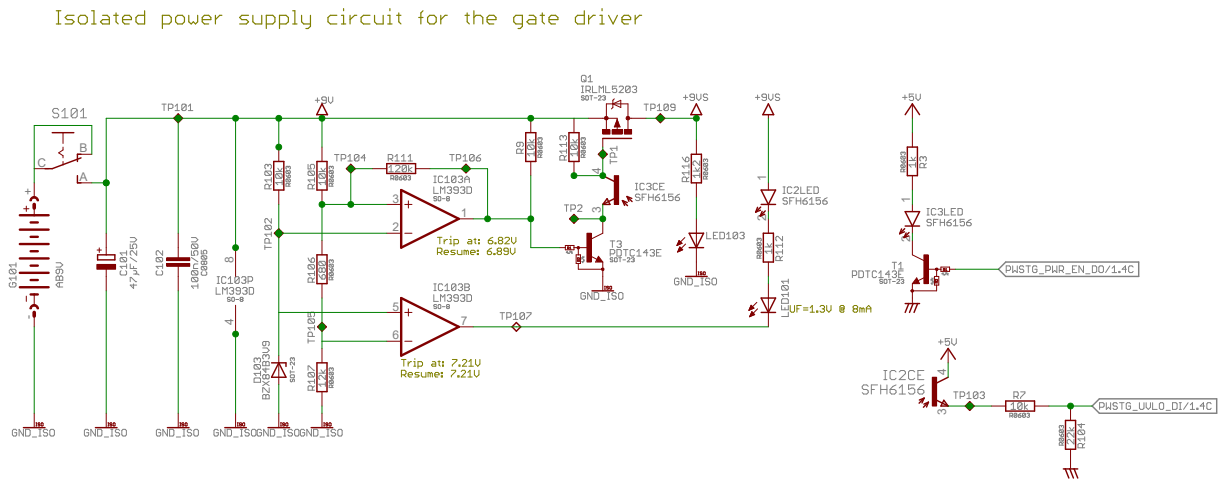
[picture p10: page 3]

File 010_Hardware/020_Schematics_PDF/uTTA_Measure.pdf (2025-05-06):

A

A

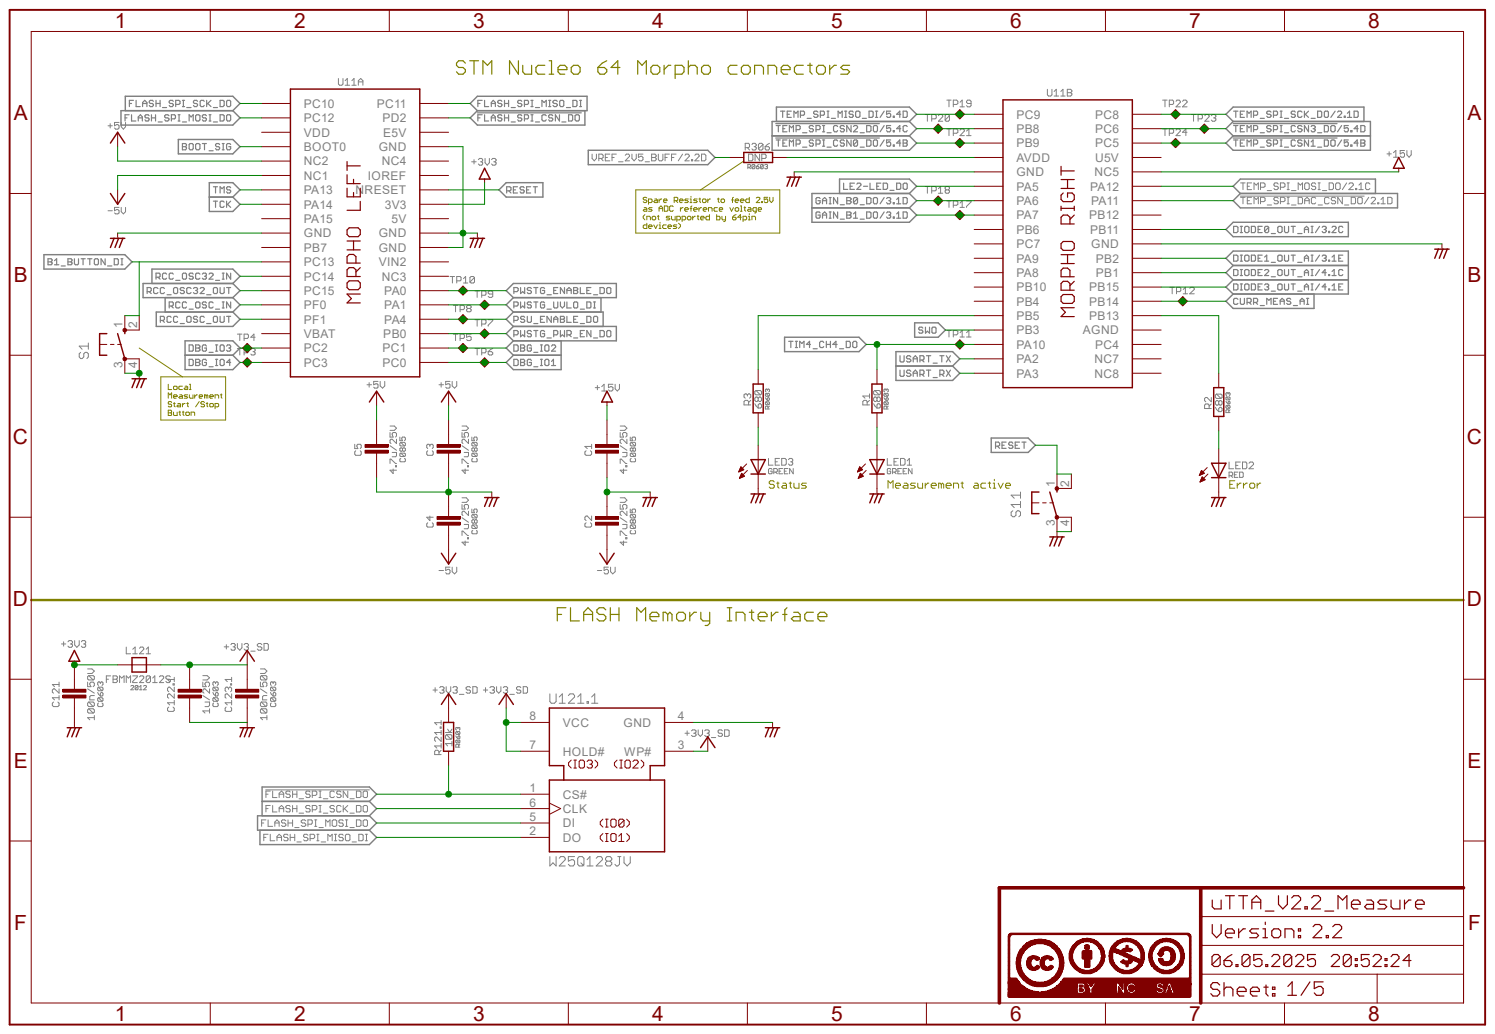
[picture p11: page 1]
CLK; GND; HOLD#; VCC; BOOT0; VDD; VIN2; VBAT; NRESET; IOREF; E5V GND; AVDD GND; PB11 GND; AGND

A

A

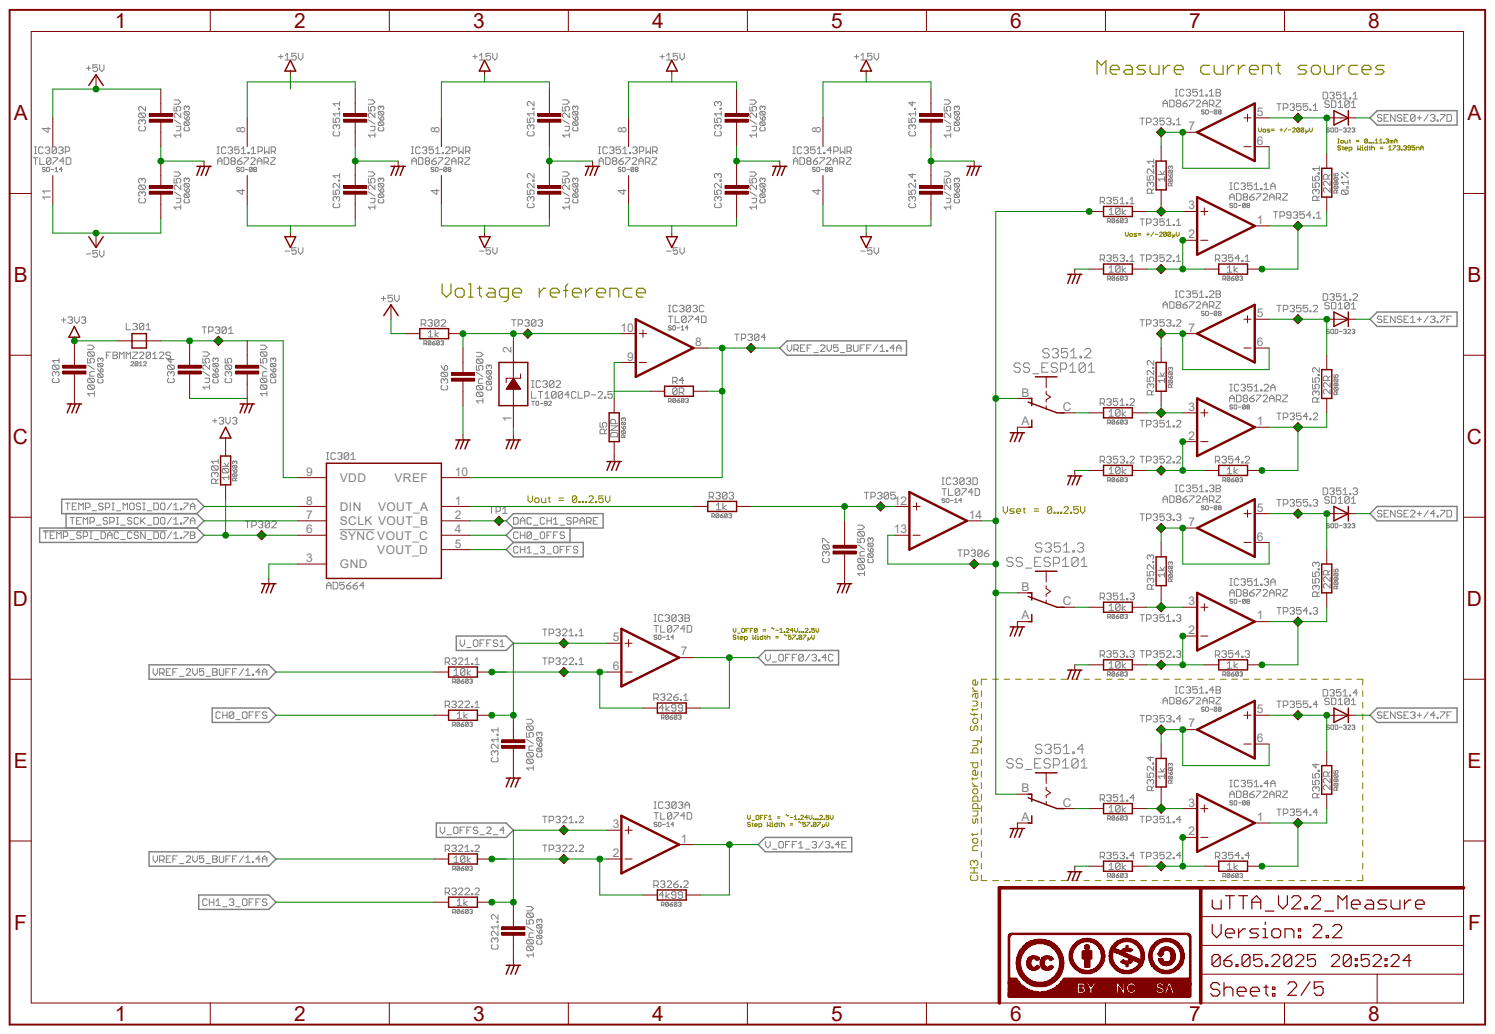
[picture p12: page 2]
VOUT_A; VOUT_B; VOUT_C; VOUT_D; VDD; VREF; GND; DIN; SCLK; SYNC

A

A

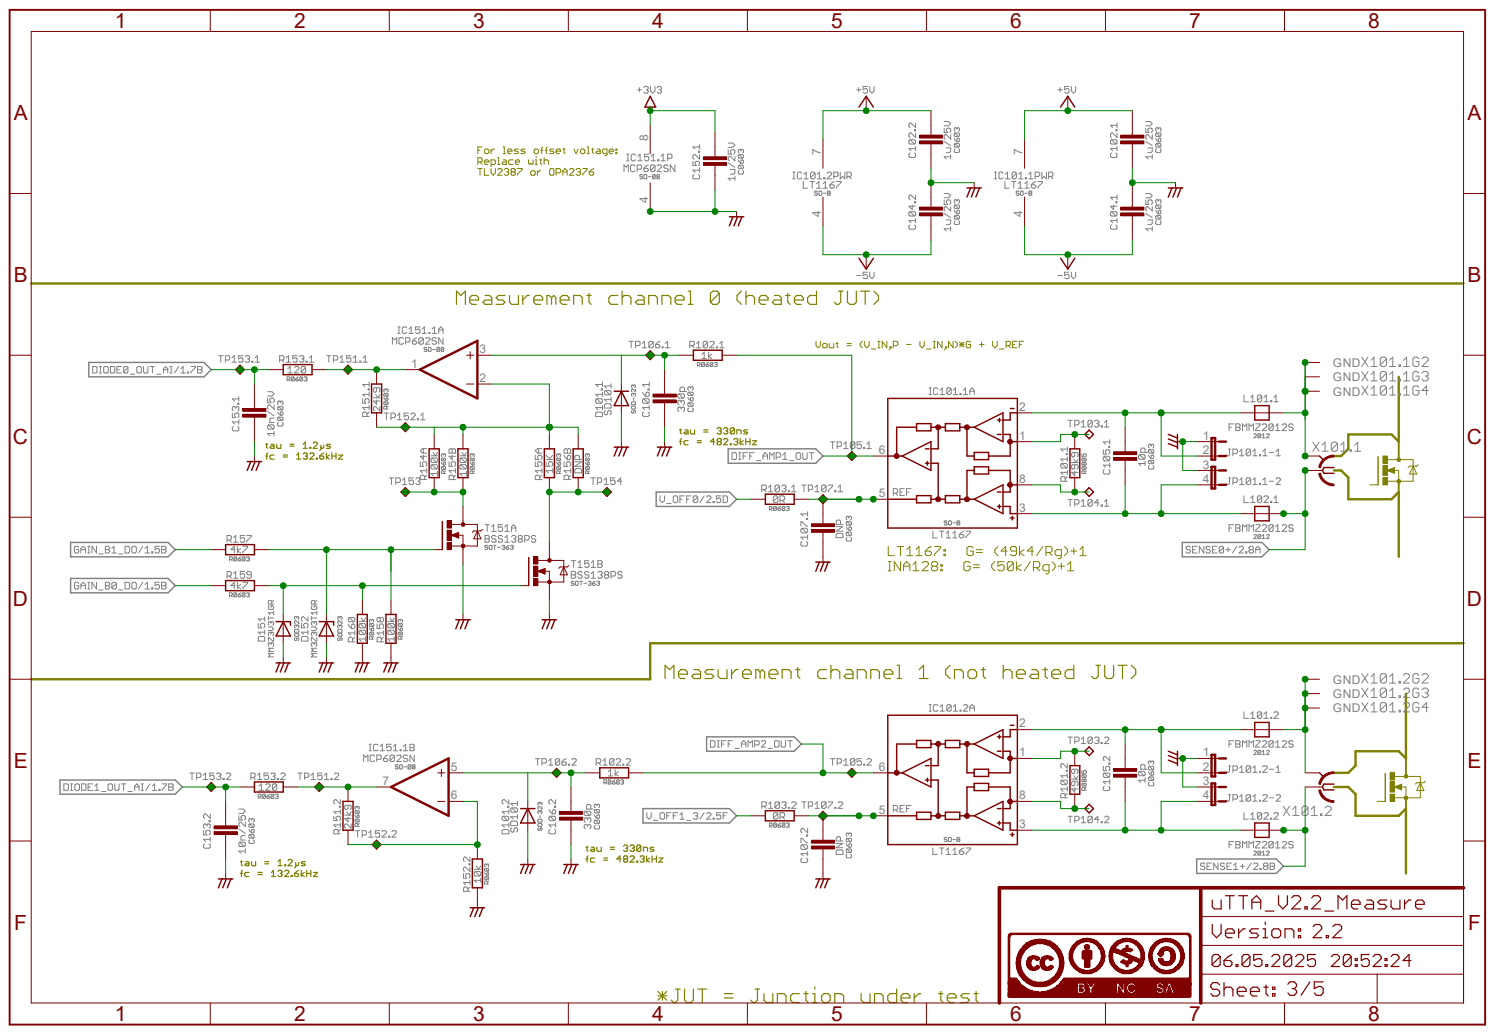
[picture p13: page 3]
GND GND GND

A

A

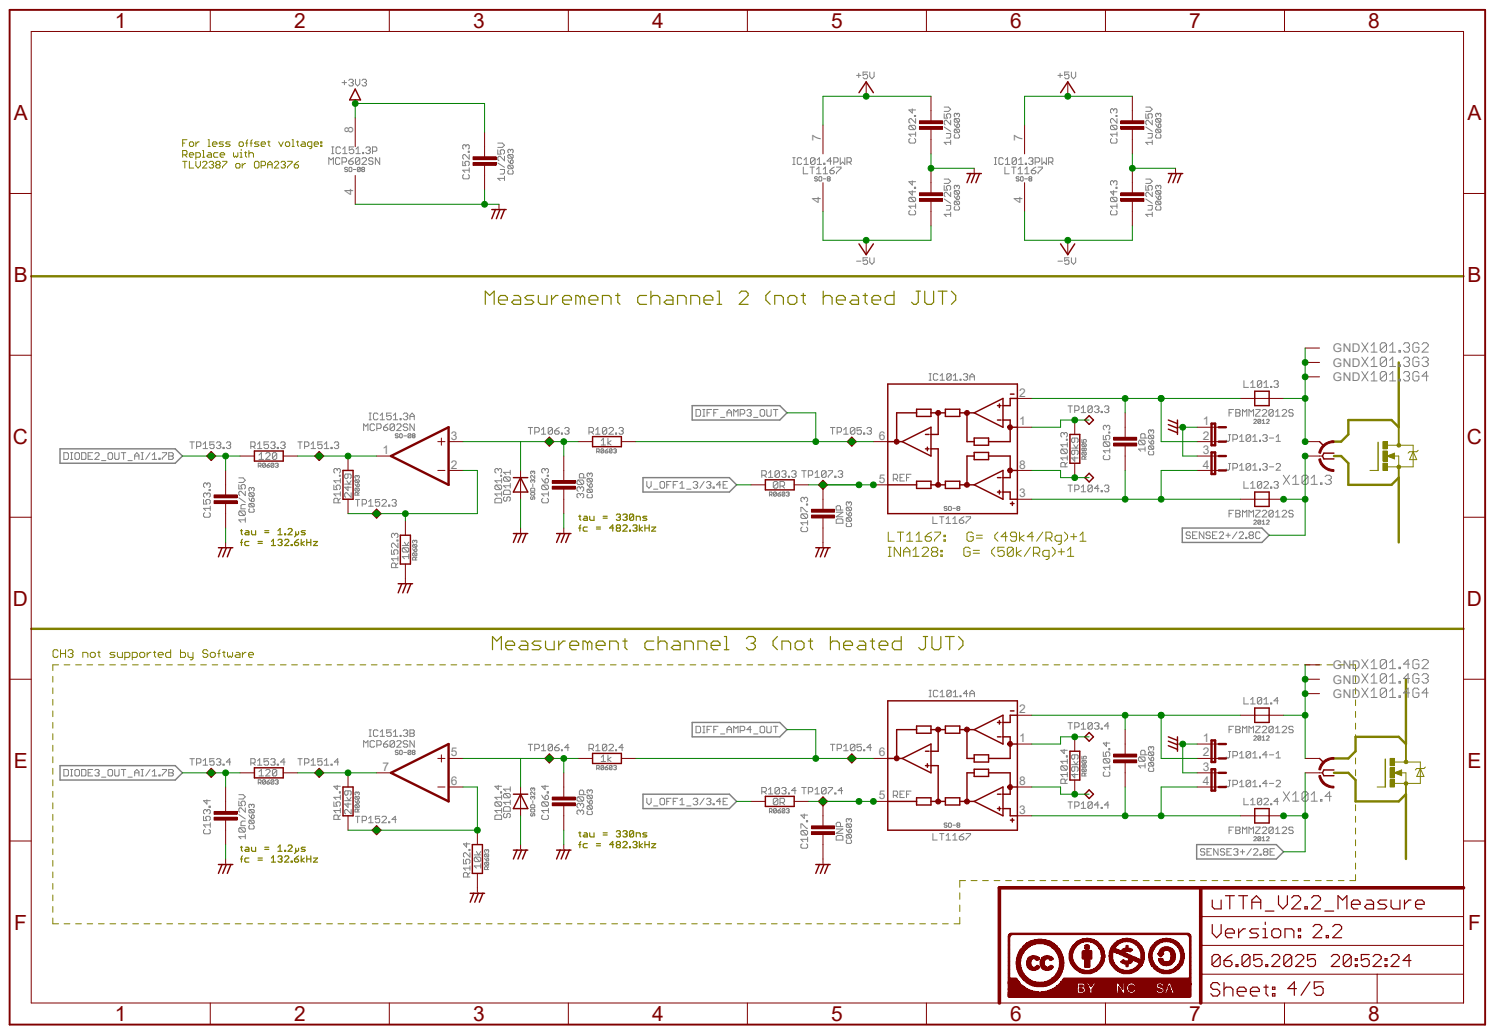
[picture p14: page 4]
GND GND GND

A

A

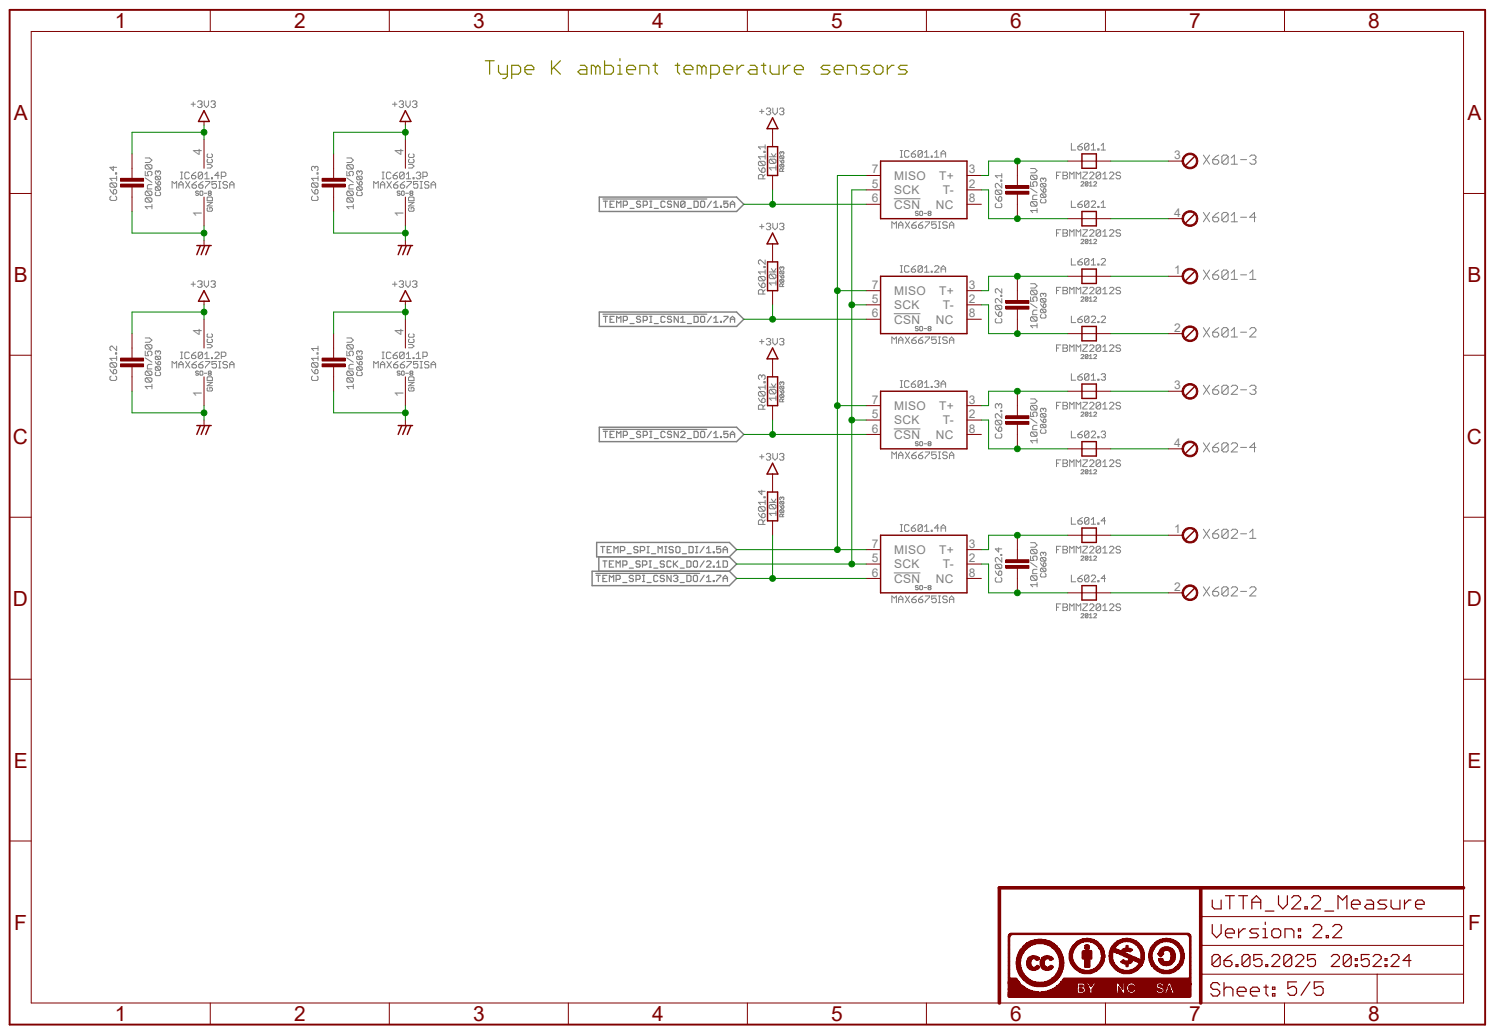
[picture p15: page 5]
3 MISO; SCK; CSN

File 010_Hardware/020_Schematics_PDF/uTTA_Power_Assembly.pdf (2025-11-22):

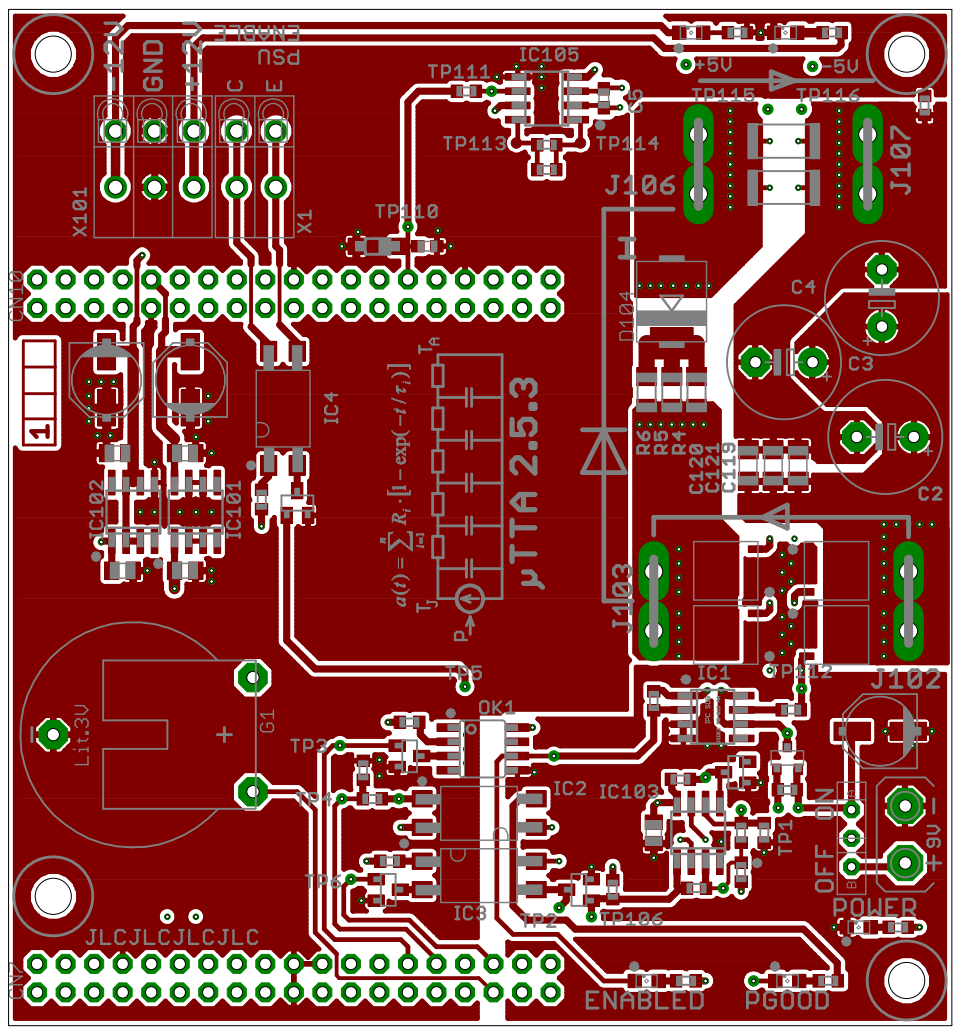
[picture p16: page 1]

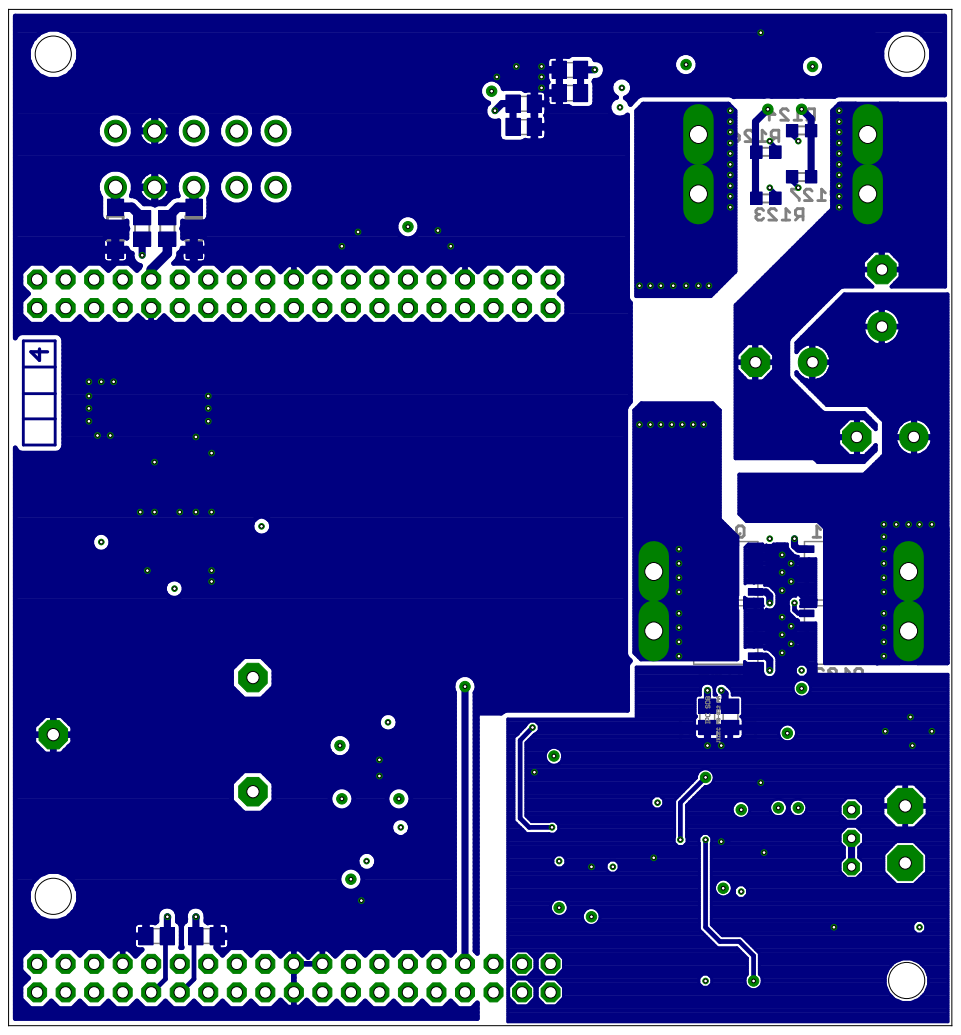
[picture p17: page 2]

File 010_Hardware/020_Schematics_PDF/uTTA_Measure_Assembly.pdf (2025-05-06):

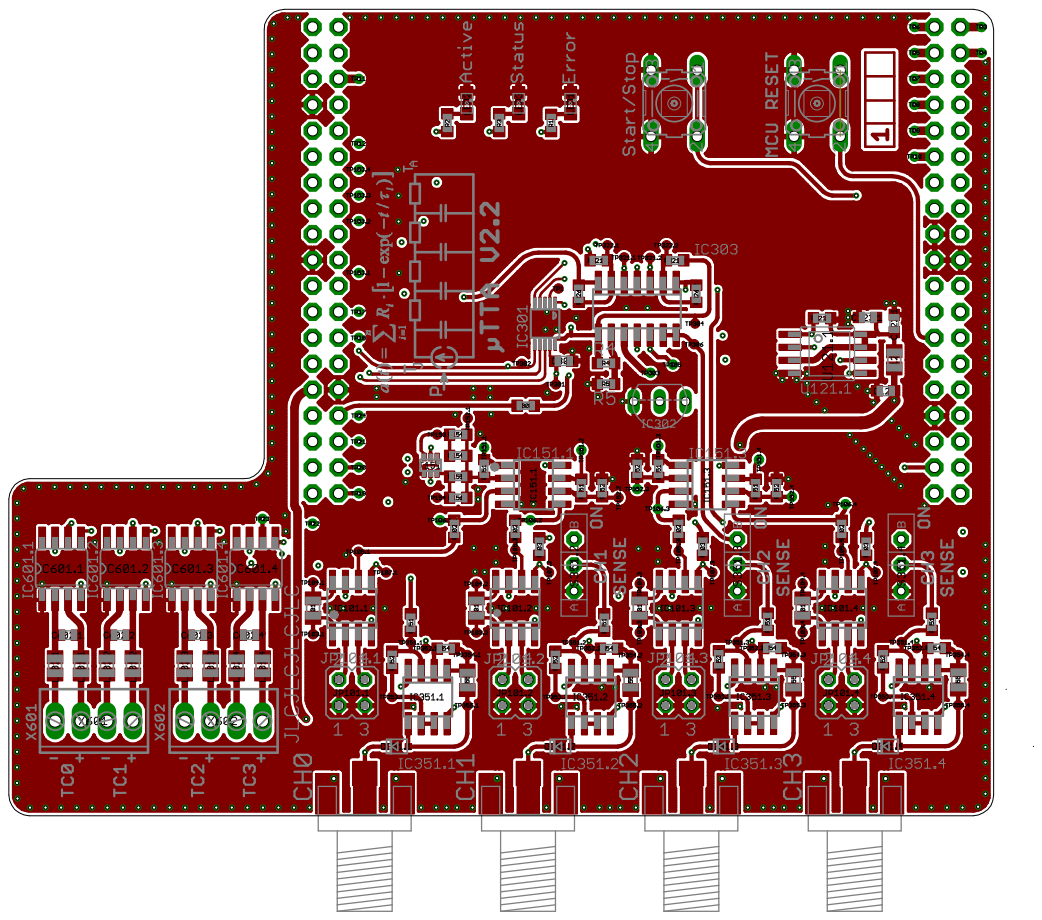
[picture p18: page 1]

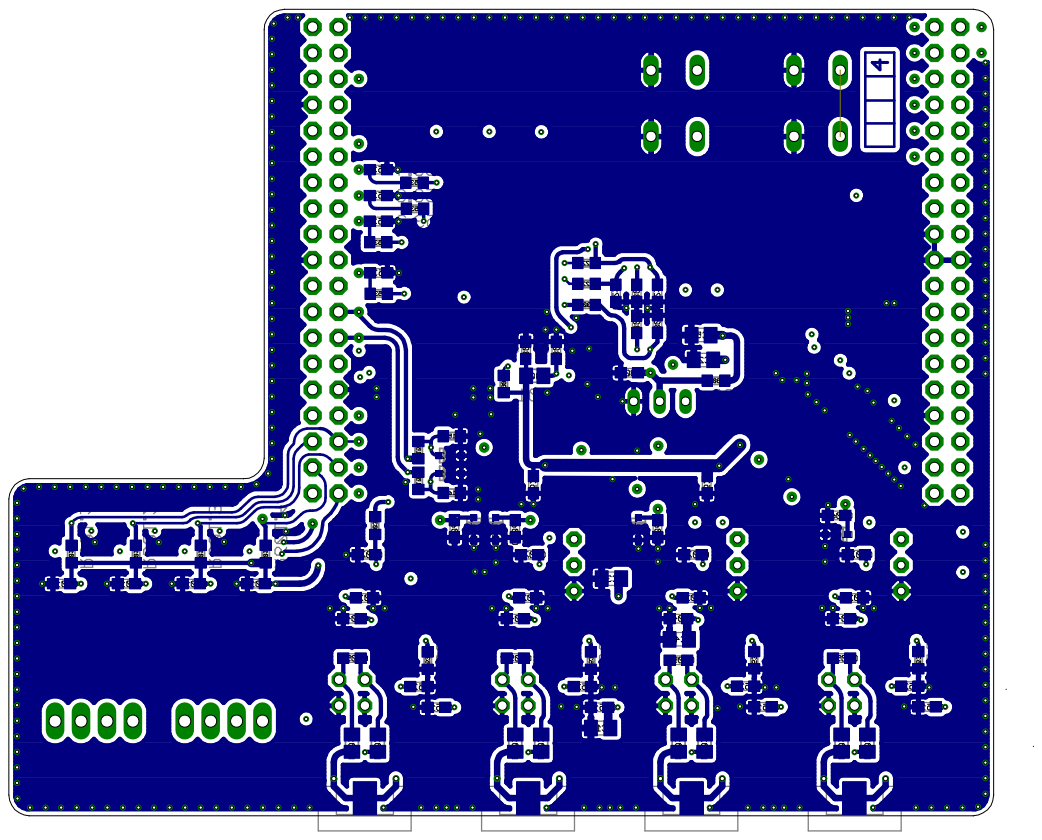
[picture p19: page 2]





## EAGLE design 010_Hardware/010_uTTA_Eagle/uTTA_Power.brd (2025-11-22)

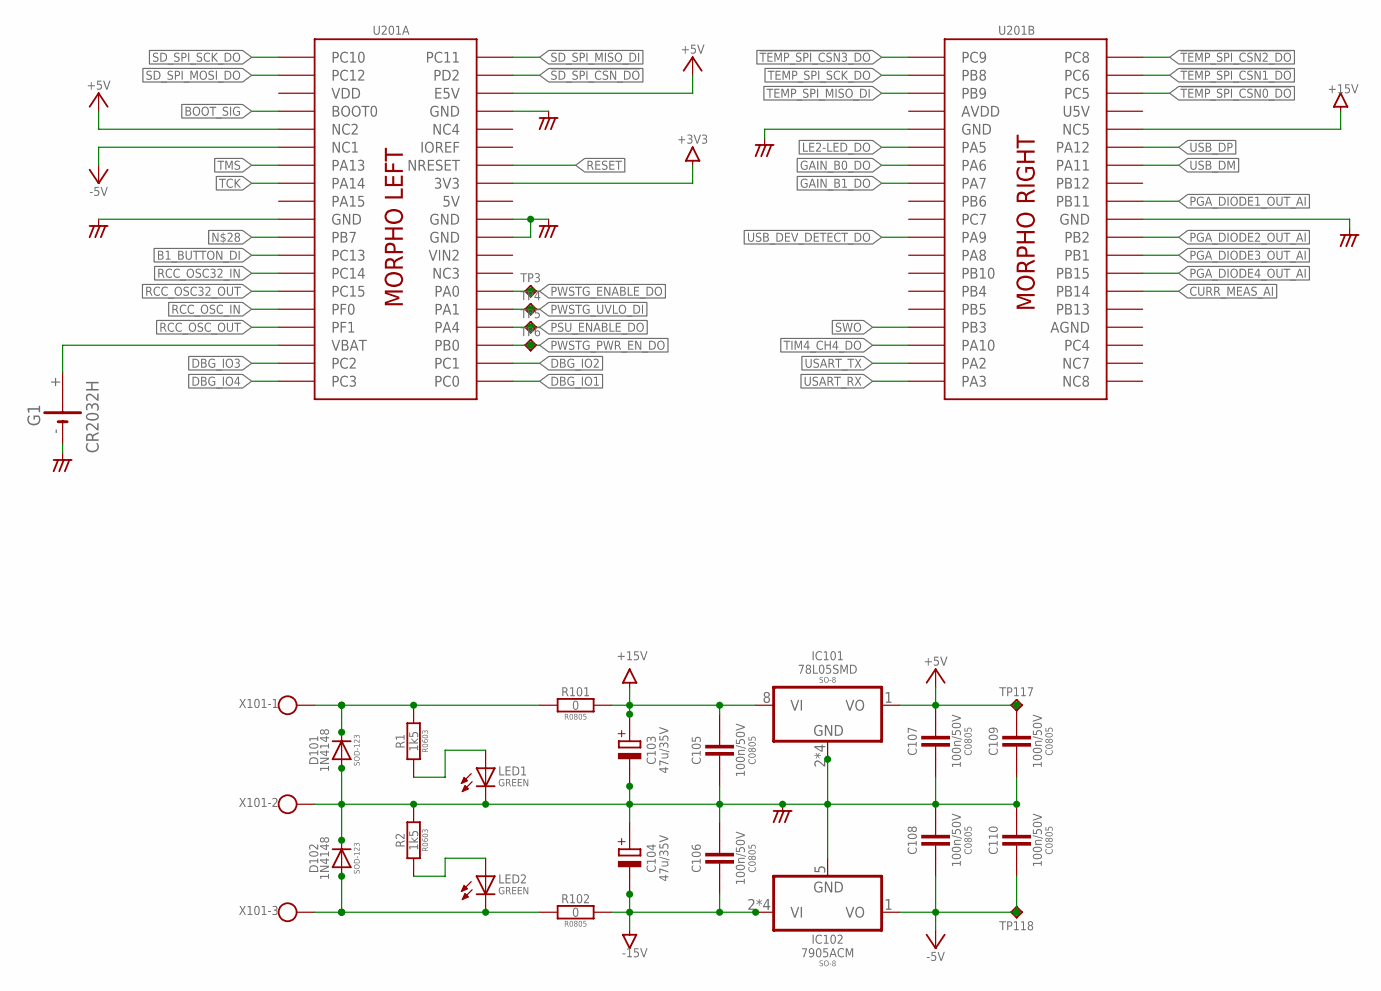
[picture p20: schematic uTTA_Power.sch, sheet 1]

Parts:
C103, C104: 47u/35V; PANASONIC_D
C105, C106, C107, C108, C109, C110: 100n/50V; C0805
D101, D102: 1N4148; SOD123
G1: CR2032H
IC101: 78L05SMD; SO08
IC102: 7905ACM; SO08
LED1, LED2: GREEN; SML0805
R1, R2: 1k5; R0603
R101, R102: 0; R0805
TP3, TP4, TP5, TP6, TP117, TP118: TPC90H30; C90H30
U201: NUCLEO_F103_BOT; NUCLEO_BRD64_LOWER
X101: AST_03_3,5MM; AST_453_3,5

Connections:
5V: U201.L_5V (5V)
!SD_SPI_CSN_DO: U201.L_PD2 (PD2)
!TEMP_SPI_CSN0_DO: U201.R_PC5 (PC5)
!TEMP_SPI_CSN1_DO: U201.R_PC6 (PC6)
!TEMP_SPI_CSN2_DO: U201.R_PC8 (PC8)
!TEMP_SPI_CSN3_DO: U201.R_PC9 (PC9)
+3V3: U201.L_3V3 (3V3)
+5V: C107.1, C109.1, IC101.1 (VO), TP117.P$1, U201.L_E5V (E5V), U201.L_NC2 (NC2); also elsewhere on the board
+15V: C103.+, C105.1, IC101.8 (VI), R101.2, U201.R_NC5 (NC5)
-5V: C108.2, C110.2, IC102.1 (VO), TP118.P$1, U201.L_NC1 (NC1); also elsewhere on the board
-15V: C104.-, C106.2, IC102.2 (VI), IC102.3 (VI), IC102.6 (VI), IC102.7 (VI), R102.2
AGND: C103.-, C104.+, C105.2, C106.1, C107.2, C108.1, C109.2, C110.1, D101.A, D102.C, G1.-, IC101.2 (GND), IC101.3 (GND), IC101.6 (GND), IC101.7 (GND), IC102.5 (GND), LED1.C, R2.1, U201.L_GND (GND), U201.L_GND3 (GND), U201.L_GND4 (GND), U201.L_GND5 (GND), U201.R_AGND (AGND), U201.R_GND7 (GND), U201.R_GND8 (GND), X101.2_1, X101.2_2; also elsewhere on the board
AVDD: U201.R_AVDD (AVDD)
B1_BUTTON_DI: U201.L_PC13 (PC13)
BOOT_SIG: U201.L_BOOT0 (BOOT0)
CURR_MEAS_AI: U201.R_PB14 (PB14); also elsewhere on the board
DBG_IO1: U201.L_PC0 (PC0)
DBG_IO2: U201.L_PC1 (PC1)
DBG_IO3: U201.L_PC2 (PC2)
DBG_IO4: U201.L_PC3 (PC3)
GAIN_B0_DO: U201.R_PA6 (PA6)
GAIN_B1_DO: U201.R_PA7 (PA7)
IN+: D101.C, R1.1, R101.1, X101.1_1, X101.1_2
IN-: D102.A, LED2.C, R102.1, X101.3_1, X101.3_2
LE2-LED_DO: U201.R_PA5 (PA5)
unnamed: G1.+, U201.L_VBAT (VBAT)
unnamed: LED1.A, R1.2
unnamed: LED2.A, R2.2
PGA_DIODE1_OUT_AI: U201.R_PB11 (PB11)
PGA_DIODE2_OUT_AI: U201.R_PB2 (PB2)
PGA_DIODE3_OUT_AI: U201.R_PB1 (PB1)
PGA_DIODE4_OUT_AI: U201.R_PB15 (PB15)
PSU_ENABLE_DO: TP5.P$1, U201.L_PA4 (PA4); also elsewhere on the board
PWSTG_ENABLE_DO: TP3.P$1, U201.L_PA0 (PA0); also elsewhere on the board
PWSTG_PWR_EN_DO: TP6.P$1, U201.L_PB0 (PB0); also elsewhere on the board
PWSTG_UVLO_DI: TP4.P$1, U201.L_PA1 (PA1); also elsewhere on the board
RCC_OSC32_IN: U201.L_PC14 (PC14)
RCC_OSC32_OUT: U201.L_PC15 (PC15)
RCC_OSC_IN: U201.L_PF0 (PF0)
RCC_OSC_OUT: U201.L_PF1 (PF1)
RESET: U201.L_RESET (NRESET)
SD_SPI_MISO_DI: U201.L_PC11 (PC11)
SD_SPI_MOSI_DO: U201.L_PC12 (PC12)
SD_SPI_SCK_DO: U201.L_PC10 (PC10)
SWO: U201.R_PB3 (PB3)
TCK: U201.L_PA14 (PA14)
TEMP_SPI_MISO_DI: U201.R_PB9 (PB9)
TEMP_SPI_SCK_DO: U201.R_PB8 (PB8)
TIM4_CH4_DO: U201.R_PA10 (PA10)
TMS: U201.L_PA13 (PA13)
U5V: U201.R_U5V (U5V)
USART_RX: U201.R_PA3 (PA3)
USART_TX: U201.R_PA2 (PA2)
USB_DEV_DETECT_DO: U201.R_PA9 (PA9)
USB_DM: U201.R_PA11 (PA11)
USB_DP: U201.R_PA12 (PA12)
VDD: U201.L_VDD (VDD)
VIN2: U201.L_VIN (VIN2)

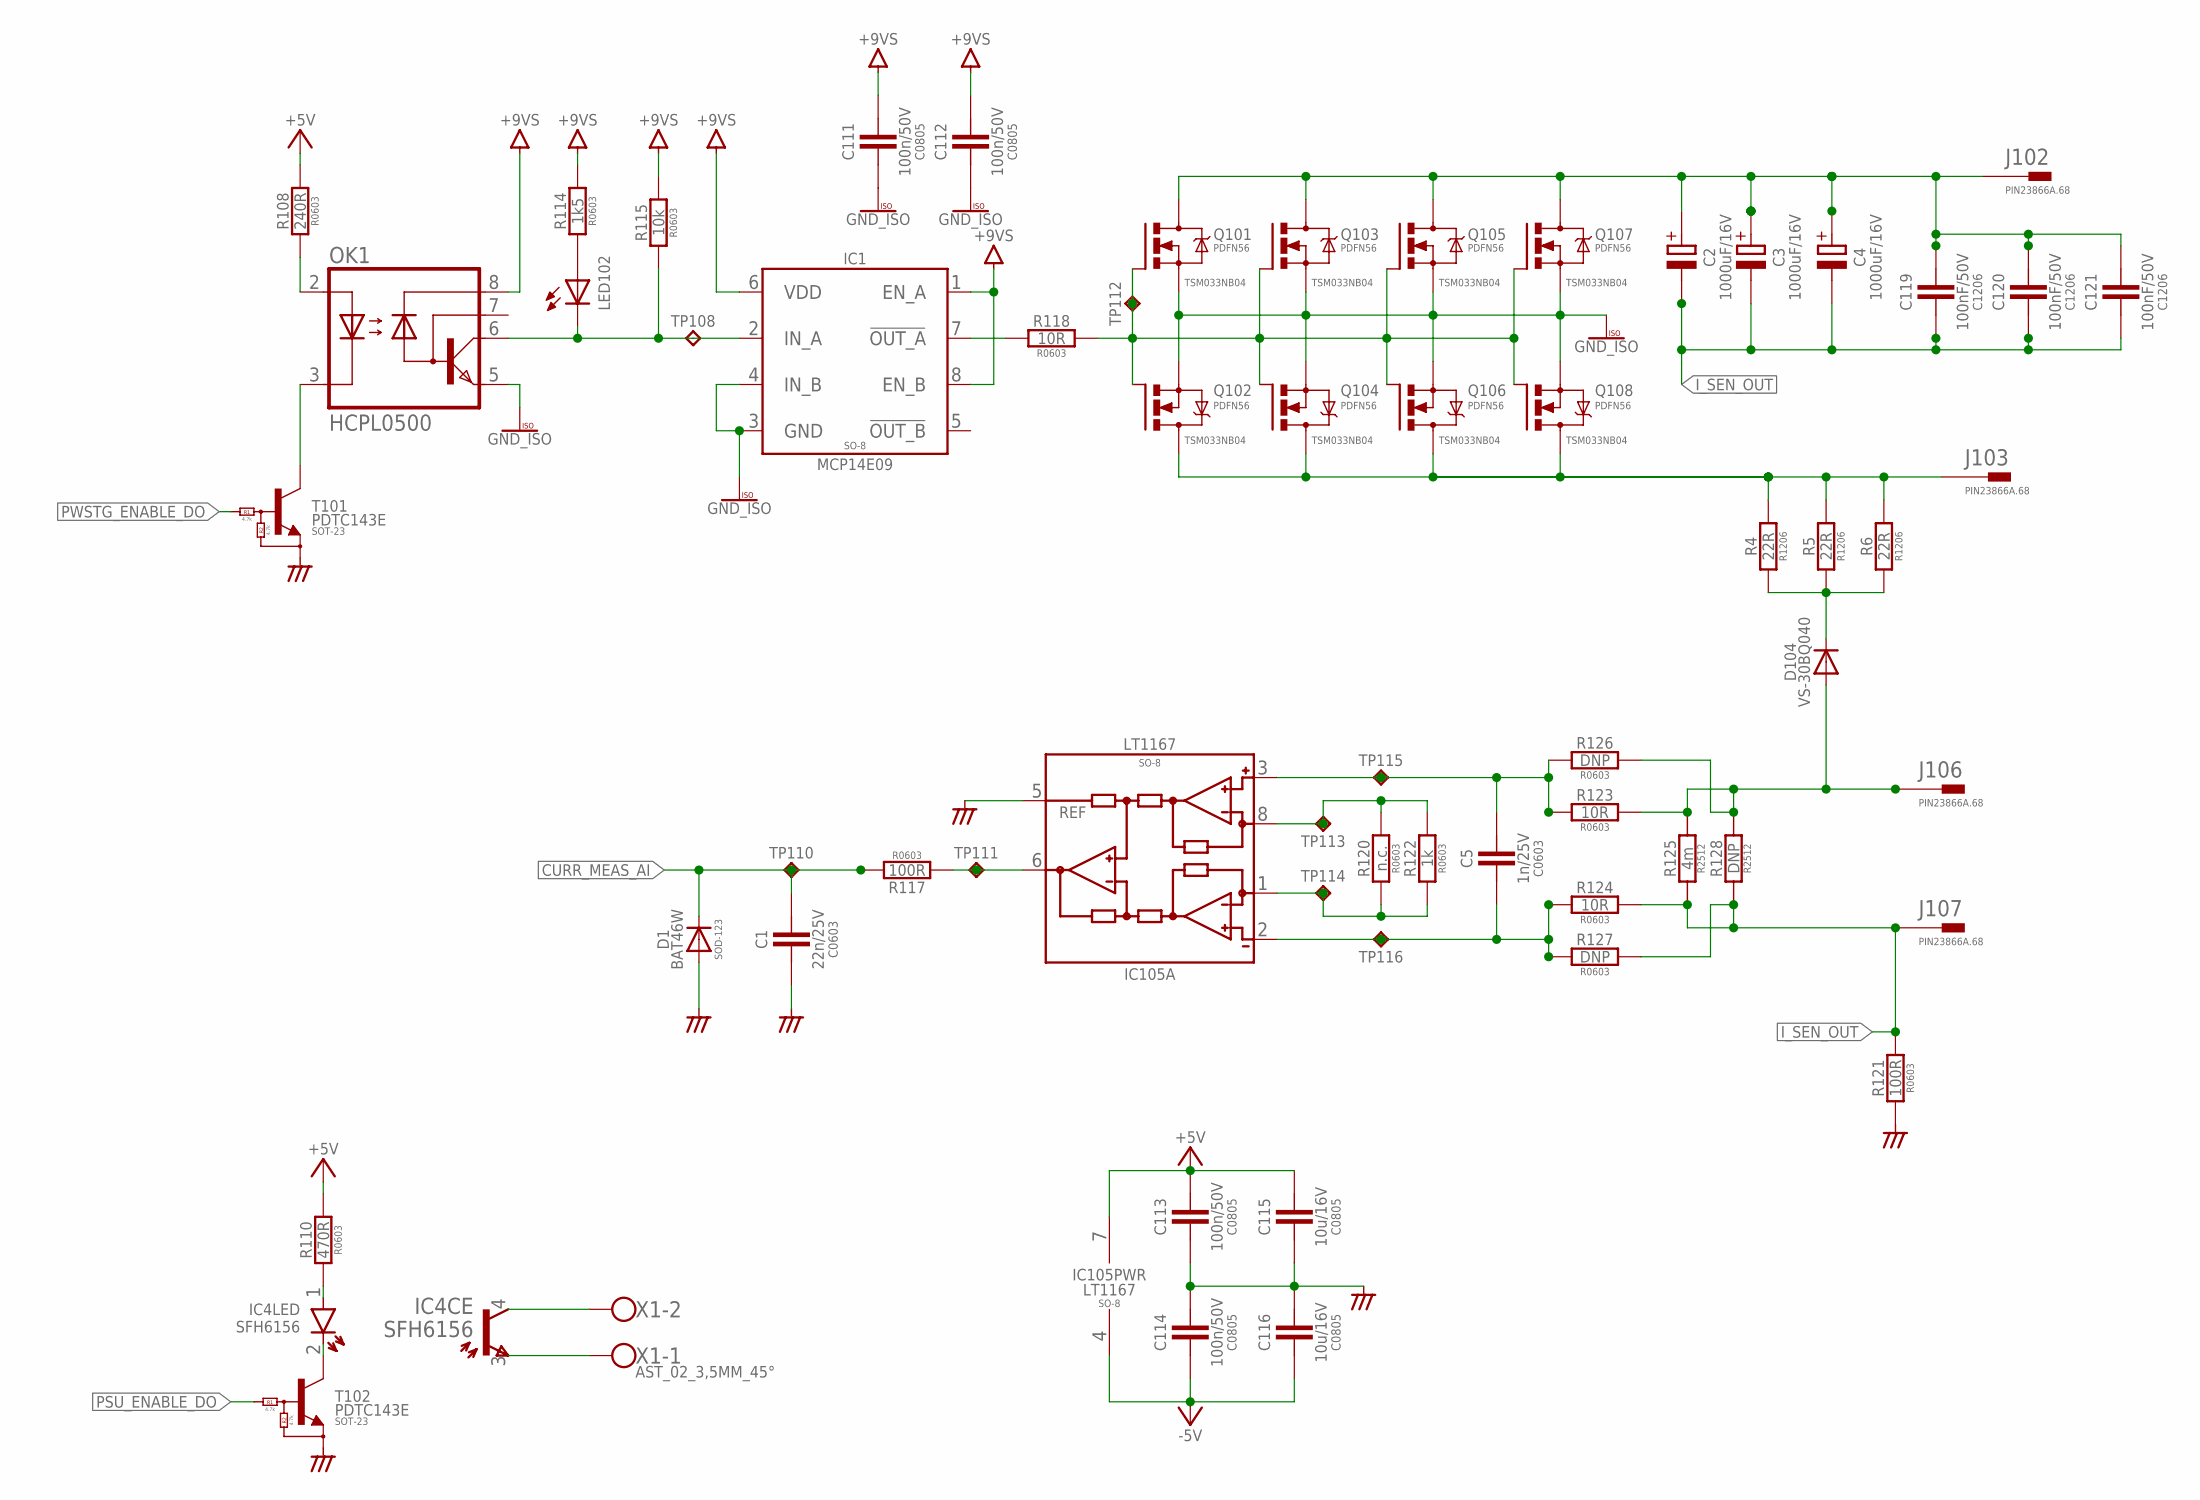
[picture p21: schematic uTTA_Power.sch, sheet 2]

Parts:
C1: 22n/25V; C0603
C2, C3, C4: 1000uF/16V; E5-10,5
C5: 1n/25V; C0603
C111, C112, C113, C114: 100n/50V; C0805
C115, C116: 10u/16V; C0805
C119, C120, C121: 100nF/50V; C1206
D1: BAT46W; SOD123
D104: VS-30BQ040; SMC
IC1: MCP14E09; SO-08
IC4: SFH6156; SFH; MPN SFH6156-4T
IC105: LT1167; SO08
J102, J103, J106, J107: PIN23866A.68; VOGT_3866A.68
LED102: LEDSML0805; SML0805
OK1: HCPL0500; SOIC08
Q101, Q102, Q103, Q104, Q105, Q106, Q107, Q108: TSM033NB04; PDFN56
R4, R5, R6: 22R; R1206
R108: 240R; R0603
R110: 470R; R0603
R114: 1k5; R0603
R115: 10k; R0603
R117, R121: 100R; R0603
R118, R123, R124: 10R; R0603
R120: n.c.; R0603
R122: 1k; R0603
R125: 4m; R2512
R126, R127: DNP; R0603
R128: DNP; R2512
T101, T102: PDTC143E; SOT23
TP108, TP110, TP111, TP112, TP115, TP116: TPC90H30; C90H30
TP113, TP114: TP; C90
X1: AST_02_3,5MM_45°; AST_452_3,5

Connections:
9V_SWITCHED: C111.1, C112.1, IC1.1 (EN_A), IC1.6 (VDD), IC1.8 (EN_B), OK1.8 (VCC), R114.1, R115.1; also elsewhere on the board
+5V: C113.1, C115.1, IC105.7 (V+), R108.1, R110.1; also elsewhere on the board
-5V: C114.2, C116.2, IC105.4 (V-); also elsewhere on the board
AGND: C1.2, C113.2, C114.1, C115.2, C116.1, D1.A, IC105.5 (REF), R121.1, T101.2 (E), T102.2 (E); also elsewhere on the board
CURR_AMP_GAIN_N: IC105.1 (RG), R120.1, R122.1, TP114.P$1
CURR_AMP_GAIN_P: IC105.8 (RG), R120.2, R122.2, TP113.P$1
CURR_AMP_OUT: IC105.6 (OUT), R117.2, TP111.P$1
CURR_MEAS_AI: C1.1, D1.C, R117.1, TP110.P$1; also elsewhere on the board
GND_ISO: C111.2, C112.2, IC1.3 (GND), IC1.4 (IN_B), OK1.5 (GND), Q101.P$1 (S), Q101.P$2 (S), Q101.P$3 (S), Q102.P$1 (S), Q102.P$2 (S), Q102.P$3 (S), Q103.P$1 (S), Q103.P$2 (S), Q103.P$3 (S), Q104.P$1 (S), Q104.P$2 (S), Q104.P$3 (S), Q105.P$1 (S), Q105.P$2 (S), Q105.P$3 (S), Q106.P$1 (S), Q106.P$2 (S), Q106.P$3 (S), Q107.P$1 (S), Q107.P$2 (S), Q107.P$3 (S), Q108.P$1 (S), Q108.P$2 (S), Q108.P$3 (S); also elsewhere on the board
I_SENSE_N: C5.2, IC105.2 (-IN), R124.2, R127.2, TP116.P$1
I_SENSE_P: C5.1, IC105.3 (+IN), R123.1, R126.1, TP115.P$1
I_SEN_IN: D104.A, J106.A1, J106.A2, R123.2, R125.2 (B), R126.2, R128.2 (B)
I_SEN_OUT: C2.-, C3.-, C4.-, C119.2, C120.2, C121.2, J107.A1, J107.A2, R121.2, R124.1, R125.1 (A), R127.1, R128.1 (A)
unnamed: C2.+, C3.+, C4.+, C119.1, C120.1, C121.1, J102.A1, J102.A2, Q101.P$5 (D), Q101.P$6 (D), Q101.P$7 (D), Q101.P$8 (D), Q101.P$9 (D), Q103.P$5 (D), Q103.P$6 (D), Q103.P$7 (D), Q103.P$8 (D), Q103.P$9 (D), Q105.P$5 (D), Q105.P$6 (D), Q105.P$7 (D), Q105.P$8 (D), Q105.P$9 (D), Q107.P$5 (D), Q107.P$6 (D), Q107.P$7 (D), Q107.P$8 (D), Q107.P$9 (D)
unnamed: IC1.7 (!OUT_A), R118.2
unnamed: Q101.P$4 (G), Q102.P$4 (G), Q103.P$4 (G), Q104.P$4 (G), Q105.P$4 (G), Q106.P$4 (G), Q107.P$4 (G), Q108.P$4 (G), R118.1, TP112.P$1
unnamed: IC4.1 (A), R110.2
unnamed: IC1.2 (IN_A), LED102.C, OK1.6 (VO), R115.2, TP108.P$1
unnamed: IC4.2 (K), T102.3 (C)
unnamed: LED102.A, R114.2
unnamed: OK1.3 (C), T101.3 (C)
unnamed: D104.C, R4.1, R5.1, R6.1
unnamed: OK1.2 (A), R108.2
unnamed: J103.A1, J103.A2, Q102.P$5 (D), Q102.P$6 (D), Q102.P$7 (D), Q102.P$8 (D), Q102.P$9 (D), Q104.P$5 (D), Q104.P$6 (D), Q104.P$7 (D), Q104.P$8 (D), Q104.P$9 (D), Q106.P$5 (D), Q106.P$6 (D), Q106.P$7 (D), Q106.P$8 (D), Q106.P$9 (D), Q108.P$5 (D), Q108.P$6 (D), Q108.P$7 (D), Q108.P$8 (D), Q108.P$9 (D), R4.2, R5.2, R6.2
OK_PSU_C: IC4.4 (C), X1.2_1, X1.2_2
OK_PSU_E: IC4.3 (E), X1.1_1, X1.1_2
PSU_ENABLE_DO: T102.1 (B); also elsewhere on the board
PWSTG_ENABLE_DO: T101.1 (B); also elsewhere on the board

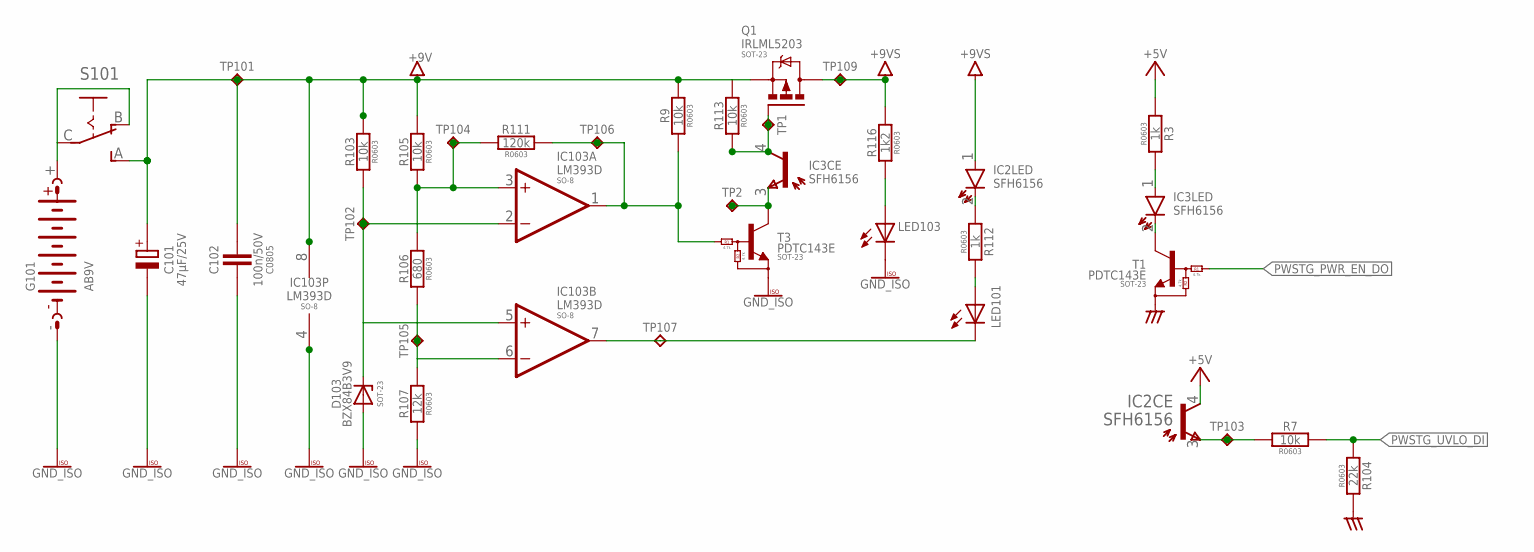
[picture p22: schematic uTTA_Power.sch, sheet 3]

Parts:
C101: 47µF/25V; PANASONIC_D
C102: 100n/50V; C0805
D103: BZX84B3V9; SOT23
G101: AB9V
IC2, IC3: SFH6156; SFH
IC103: LM393D; SO08
LED101, LED103: LEDSML0805; SML0805
Q1: IRLML5203; MICRO3
R3, R112: 1k; R0603
R7, R9, R103, R105, R113: 10k; R0603
R104: 22k; R0603
R106: 680; R0603
R107: 12k; R0603
R111: 120k; R0603
R116: 1k2; R0603
S101: SS_ESP101
T1, T3: PDTC143E; SOT23
TP1, TP2, TP101, TP102, TP103, TP104, TP105, TP106, TP107, TP109: TPC90H30; C90H30

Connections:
9V_SWITCHED: IC2.1 (A), Q1.3 (D), R116.1, TP109.P$1; also elsewhere on the board
+5V: IC2.4 (C), R3.2; also elsewhere on the board
+9V: C101.+, C102.1, IC103.8 (V+), Q1.2 (S), R9.1, R103.1, R105.1, R113.1, S101.A (S), TP101.P$1
AGND: R104.2, T1.2 (E); also elsewhere on the board
GND_ISO: C101.-, C102.2, D103.1 (A), G101.-, IC103.4 (V-), LED103.C, R107.2, T3.2 (E); also elsewhere on the board
unnamed: IC103.7 (OUT), LED101.C, TP107.P$1
unnamed: G101.+, S101.B (O), S101.C
unnamed: LED103.A, R116.2
unnamed: IC3.4 (C), Q1.1 (G), R113.2, TP1.P$1
unnamed: IC3.2 (K), T1.3 (C)
unnamed: IC3.1 (A), R3.1
unnamed: IC2.3 (E), R7.1, TP103.P$1
unnamed: IC3.3 (E), T3.3 (C), TP2.P$1
unnamed: D103.3 (C), IC103.2 (-IN), IC103.5 (+IN), R103.2, TP102.P$1
unnamed: IC103.6 (-IN), R106.2, R107.1, TP105.P$1
unnamed: IC103.3 (+IN), R105.2, R106.1, R111.2, TP104.P$1
unnamed: IC2.2 (K), R112.2
unnamed: IC103.1 (OUT), R9.2, R111.1, T3.1 (B), TP106.P$1
unnamed: LED101.A, R112.1
PWSTG_PWR_EN_DO: T1.1 (B); also elsewhere on the board
PWSTG_UVLO_DI: R7.2, R104.1; also elsewhere on the board

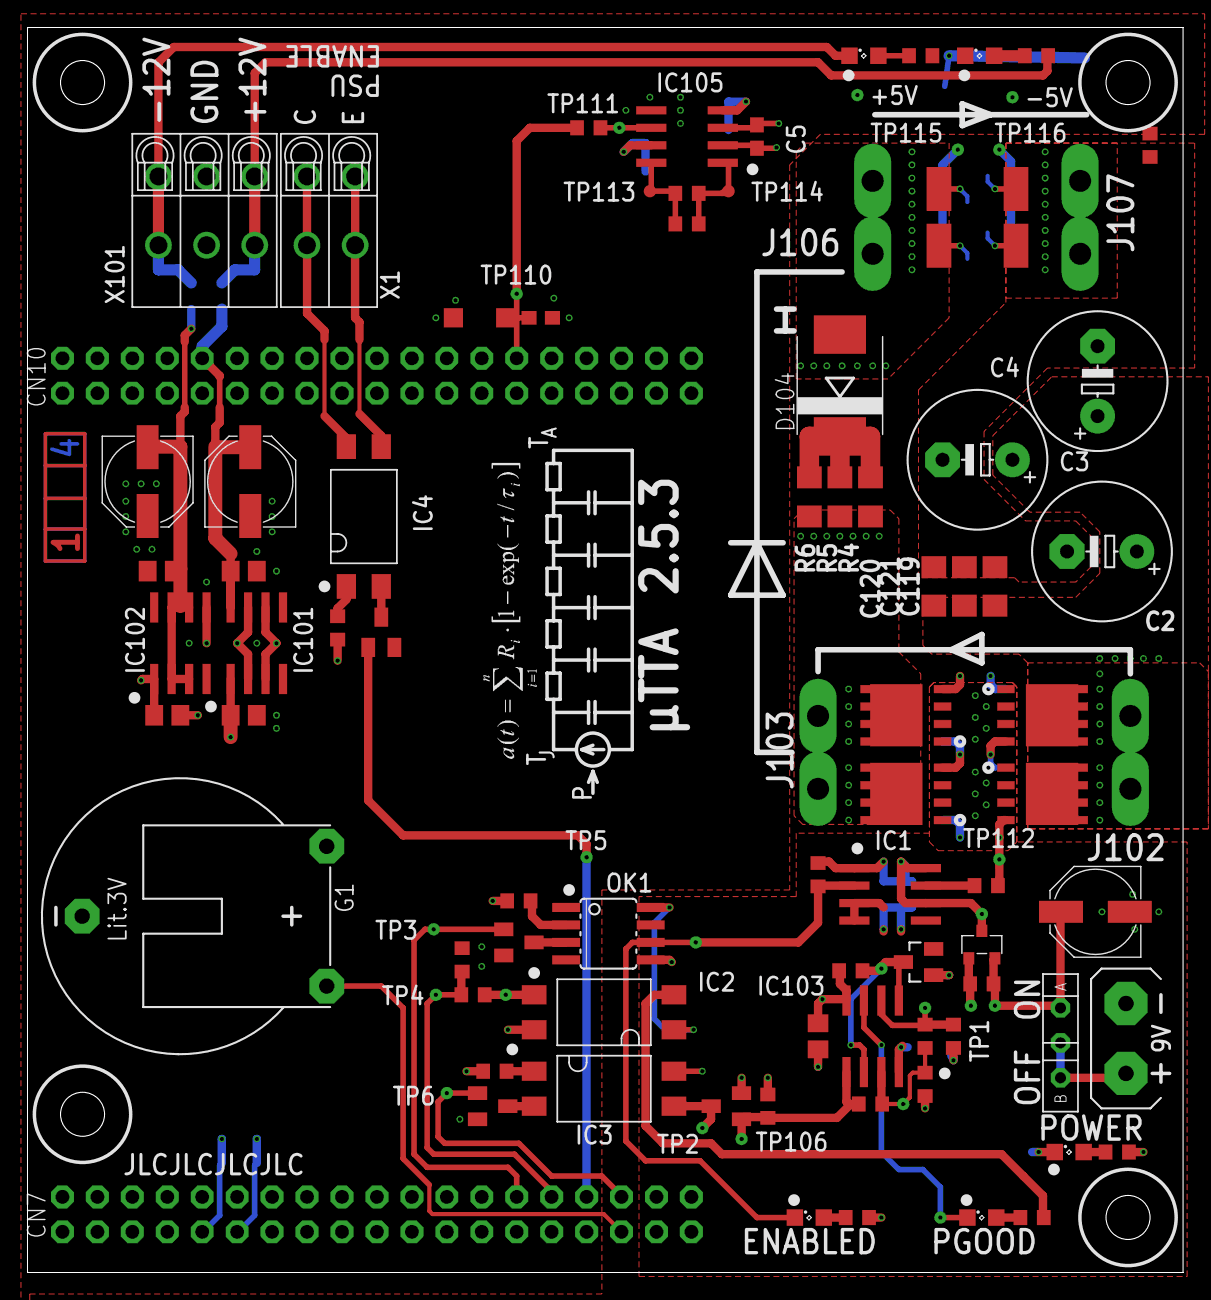
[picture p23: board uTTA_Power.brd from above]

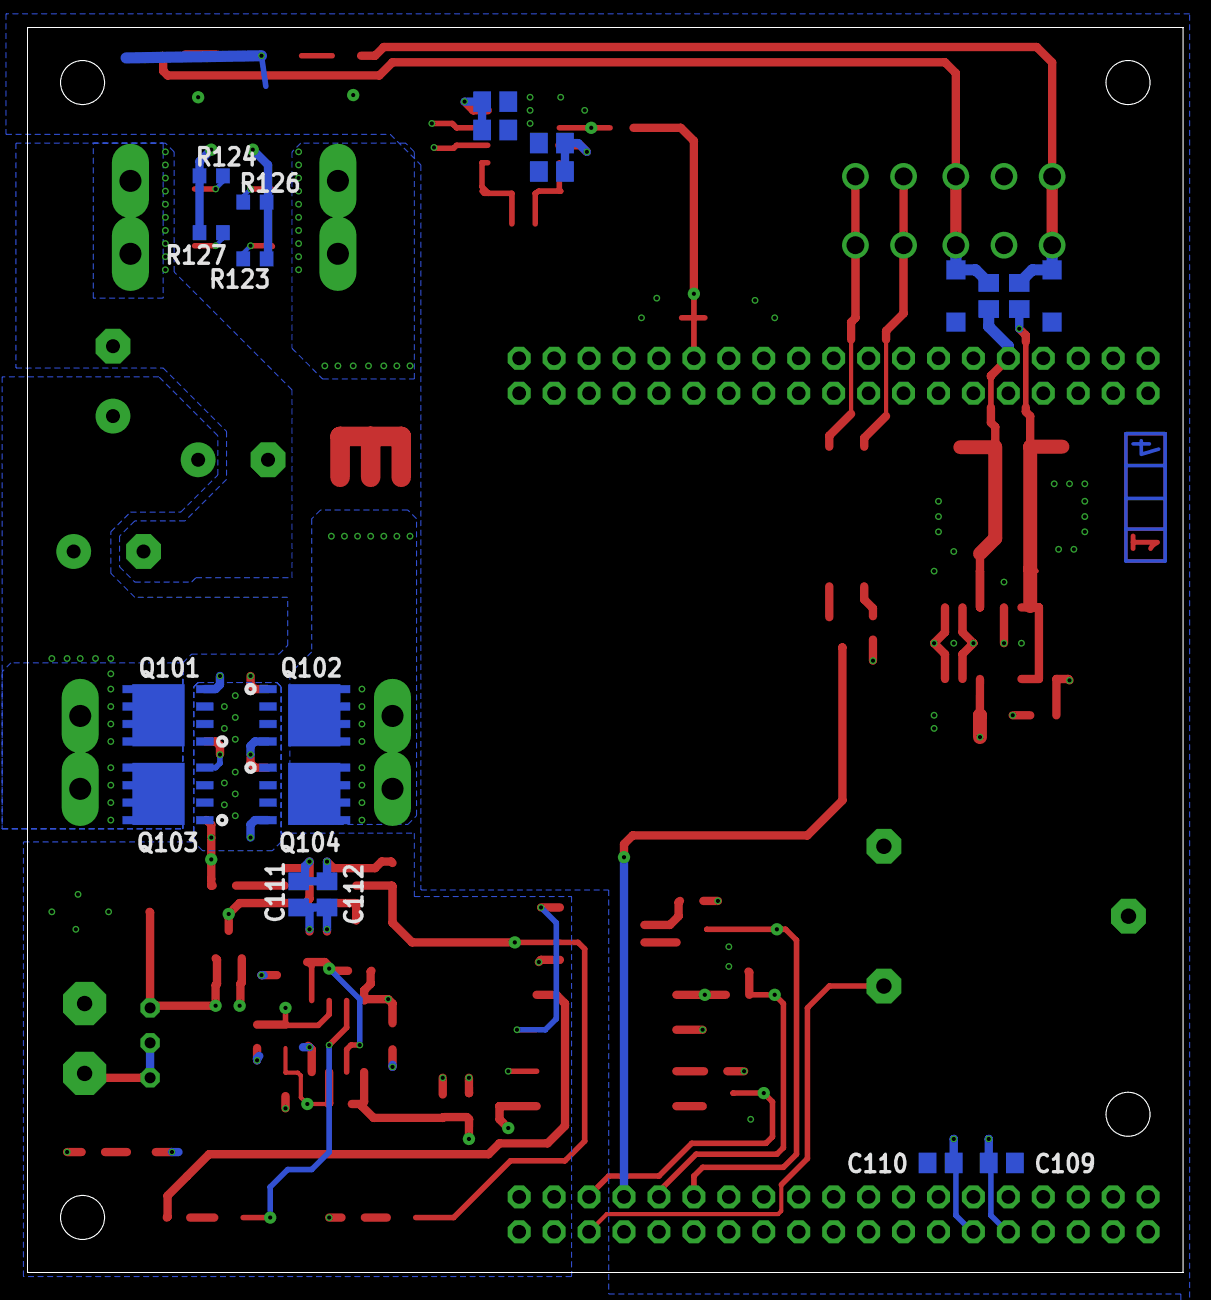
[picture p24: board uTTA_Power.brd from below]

Board: 4 copper layers, 84.0 x 90.5 mm, 125 parts (20 on the bottom side), 52 nets.

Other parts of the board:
U$7: A4_LOC_CC_BY_NC_SA

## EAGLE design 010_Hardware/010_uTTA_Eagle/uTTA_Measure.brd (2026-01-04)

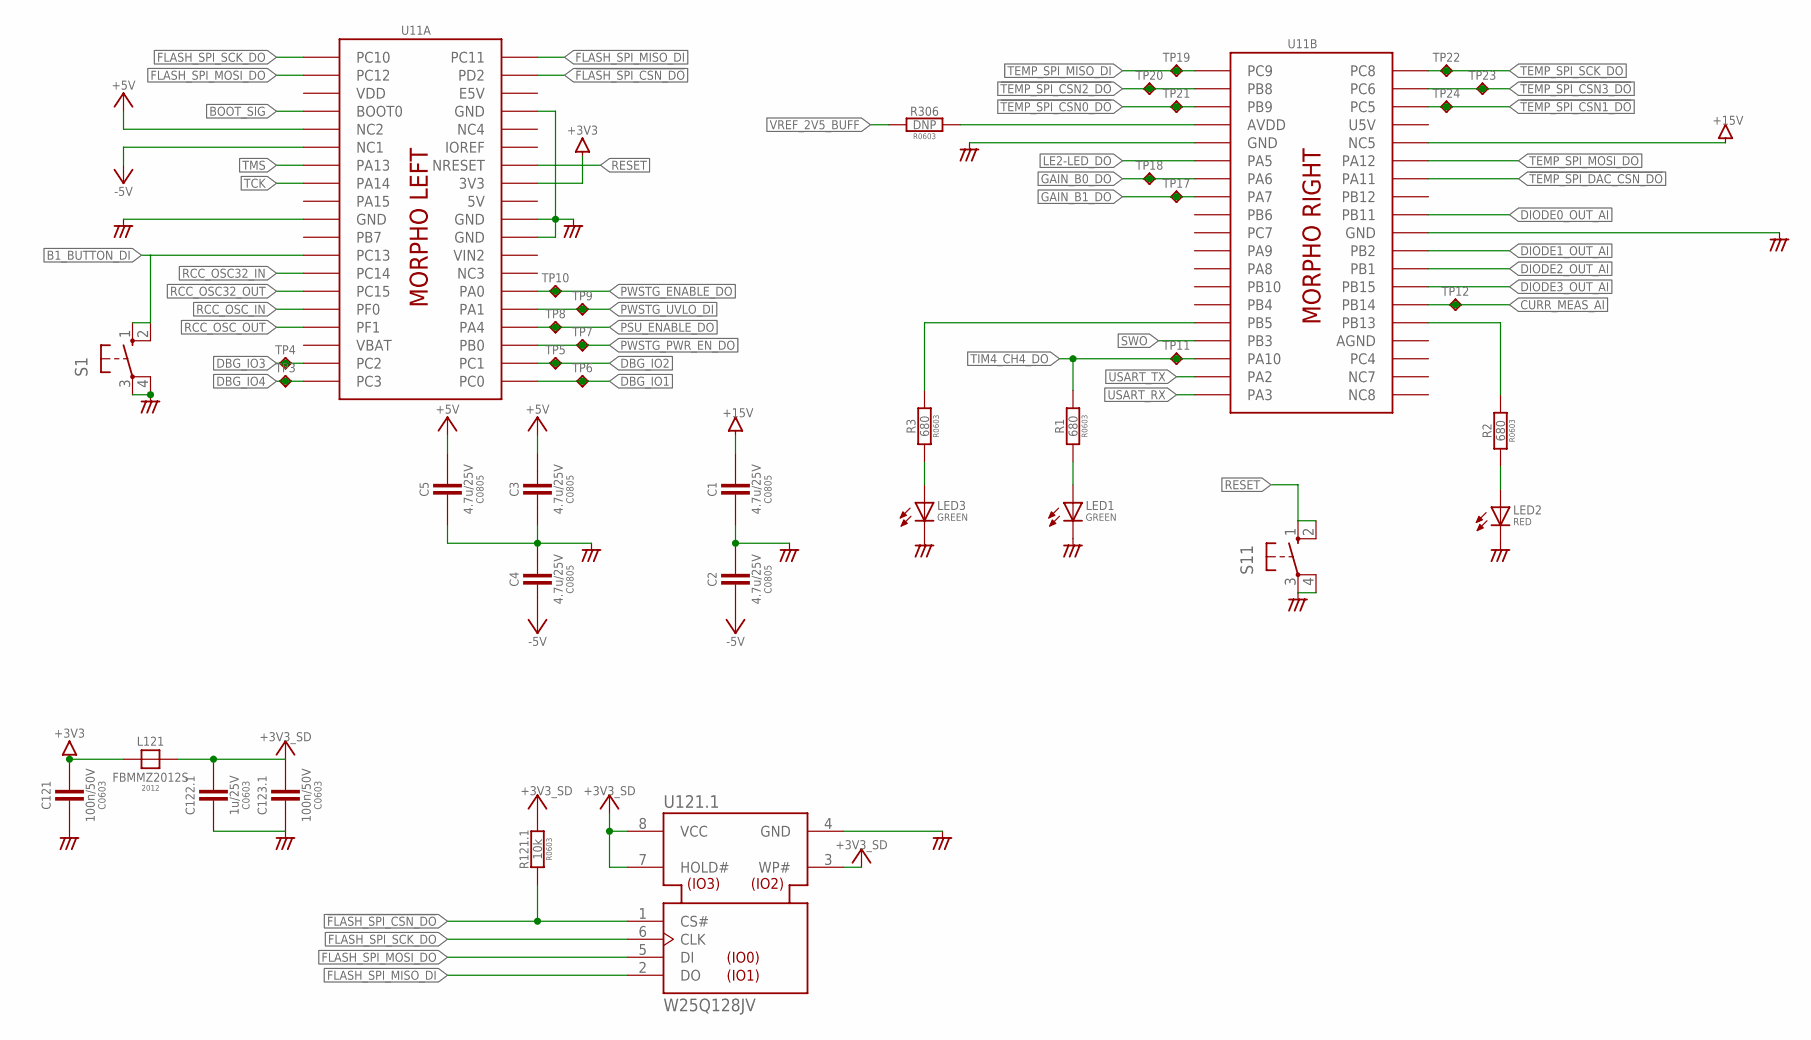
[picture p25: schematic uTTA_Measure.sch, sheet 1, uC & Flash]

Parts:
C1, C2, C3, C4, C5: 4.7u/25V; C0805
C121, C123.1: 100n/50V; C0603
C122.1: 1u/25V; C0603
L121: FBMMZ2012S; FB2012
LED1, LED3: GREEN; SML0805
LED2: RED; SML0805
R1, R2, R3: 680; R0603
R121.1: 10k; R0603
R306: DNP; R0603
S1: 10-XX; B3F-10XX; MPN B3F-1000
S11: 10-XX; B3F-10XX
TP3, TP4, TP5, TP6, TP7, TP8, TP9, TP10, TP11, TP12, TP17, TP18, TP19, TP20, TP21, TP22, TP23, TP24: TPC90H30; C90H30
U11: NUCLEO_F103_BOT; NUCLEO_BRD64_LOWER
U121.1: W25Q128JV; SO08W

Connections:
5V: U11.L_5V (5V)
!FLASH_SPI_CSN_DO: R121.1.2, U11.L_PD2 (PD2), U121.1.1 (CS#)
!TEMP_SPI_CSN0_DO: TP21.P$1, U11.R_PB9 (PB9); also elsewhere on the board
!TEMP_SPI_CSN1_DO: TP24.P$1, U11.R_PC5 (PC5); also elsewhere on the board
!TEMP_SPI_CSN2_DO: TP20.P$1, U11.R_PB8 (PB8); also elsewhere on the board
!TEMP_SPI_CSN3_DO: TP23.P$1, U11.R_PC6 (PC6); also elsewhere on the board
!TEMP_SPI_DAC_CSN_DO: U11.R_PA11 (PA11); also elsewhere on the board
+3V3: C121.1, L121.1, U11.L_3V3 (3V3); also elsewhere on the board
+5V: C3.1, C5.1, U11.L_NC2 (NC2); also elsewhere on the board
+5V/4: C122.1.1, C123.1.1, L121.2, R121.1.1, U121.1.3 (WP#), U121.1.7 (HOLD#), U121.1.8 (VCC)
+15V: C1.1, U11.R_NC5 (NC5); also elsewhere on the board
-5V: C2.2, C4.2, U11.L_NC1 (NC1); also elsewhere on the board
AGND: C1.2, C2.1, C3.2, C4.1, C5.2, C121.2, C122.1.2, C123.1.2, LED1.C, LED2.C, LED3.C, S1.3, S1.4 (P1), S11.3, S11.4 (P1), U11.L_GND (GND), U11.L_GND3 (GND), U11.L_GND4 (GND), U11.L_GND5 (GND), U11.R_AGND (AGND), U11.R_GND7 (GND), U11.R_GND8 (GND), U121.1.4 (GND); also elsewhere on the board
B1_BUTTON_DI: S1.1 (S), S1.2 (S1), U11.L_PC13 (PC13)
BOOT_SIG: U11.L_BOOT0 (BOOT0)
CURR_MEAS_AI: TP12.P$1, U11.R_PB14 (PB14)
DBG_IO1: TP6.P$1, U11.L_PC0 (PC0)
DBG_IO2: TP5.P$1, U11.L_PC1 (PC1)
DBG_IO3: TP4.P$1, U11.L_PC2 (PC2)
DBG_IO4: TP3.P$1, U11.L_PC3 (PC3)
DIODE0_OUT_AI: U11.R_PB11 (PB11); also elsewhere on the board
DIODE1_OUT_AI: U11.R_PB2 (PB2); also elsewhere on the board
DIODE2_OUT_AI: U11.R_PB1 (PB1); also elsewhere on the board
DIODE3_OUT_AI: U11.R_PB15 (PB15); also elsewhere on the board
E5V: U11.L_E5V (E5V)
FLASH_SPI_MISO_DI: U11.L_PC11 (PC11), U121.1.2 (DO)
FLASH_SPI_MOSI_DO: U11.L_PC12 (PC12), U121.1.5 (DI)
FLASH_SPI_SCK_DO: U11.L_PC10 (PC10), U121.1.6 (CLK)
GAIN_B0_DO: TP18.P$1, U11.R_PA6 (PA6); also elsewhere on the board
GAIN_B1_DO: TP17.P$1, U11.R_PA7 (PA7); also elsewhere on the board
LE2-LED_DO: U11.R_PA5 (PA5)
unnamed: LED2.A, R2.2
unnamed: LED3.A, R3.2
unnamed: LED1.A, R1.2
PSU_ENABLE_DO: TP8.P$1, U11.L_PA4 (PA4)
PWSTG_ENABLE_DO: TP10.P$1, U11.L_PA0 (PA0)
PWSTG_PWR_EN_DO: TP7.P$1, U11.L_PB0 (PB0)
PWSTG_UVLO_DI: TP9.P$1, U11.L_PA1 (PA1)
RCC_OSC32_IN: U11.L_PC14 (PC14)
RCC_OSC32_OUT: U11.L_PC15 (PC15)
RCC_OSC_IN: U11.L_PF0 (PF0)
RCC_OSC_OUT: U11.L_PF1 (PF1)
RESET: S11.1 (S), S11.2 (S1), U11.L_RESET (NRESET)
SWO: U11.R_PB3 (PB3)
TCK: U11.L_PA14 (PA14)
TEMP_SPI_MISO_DI: TP19.P$1, U11.R_PC9 (PC9); also elsewhere on the board
TEMP_SPI_MOSI_DO: U11.R_PA12 (PA12); also elsewhere on the board
TEMP_SPI_SCK_DO: TP22.P$1, U11.R_PC8 (PC8); also elsewhere on the board
TIM4_CH4_DO: R1.1, TP11.P$1, U11.R_PA10 (PA10)
TIM4_CH4_DO1: R2.1, U11.R_PB13 (PB13)
TIM4_CH4_DO2: R3.1, U11.R_PB5 (PB5)
TMS: U11.L_PA13 (PA13)
U5V: U11.R_U5V (U5V)
USART_RX: U11.R_PA3 (PA3)
USART_TX: U11.R_PA2 (PA2)
VBAT: U11.L_VBAT (VBAT)
VDD: U11.L_VDD (VDD)
VIN2: U11.L_VIN (VIN2)
VREF_2V5_ADCREF: R306.2, U11.R_AVDD (AVDD)
VREF_2V5_BUFF: R306.1; also elsewhere on the board

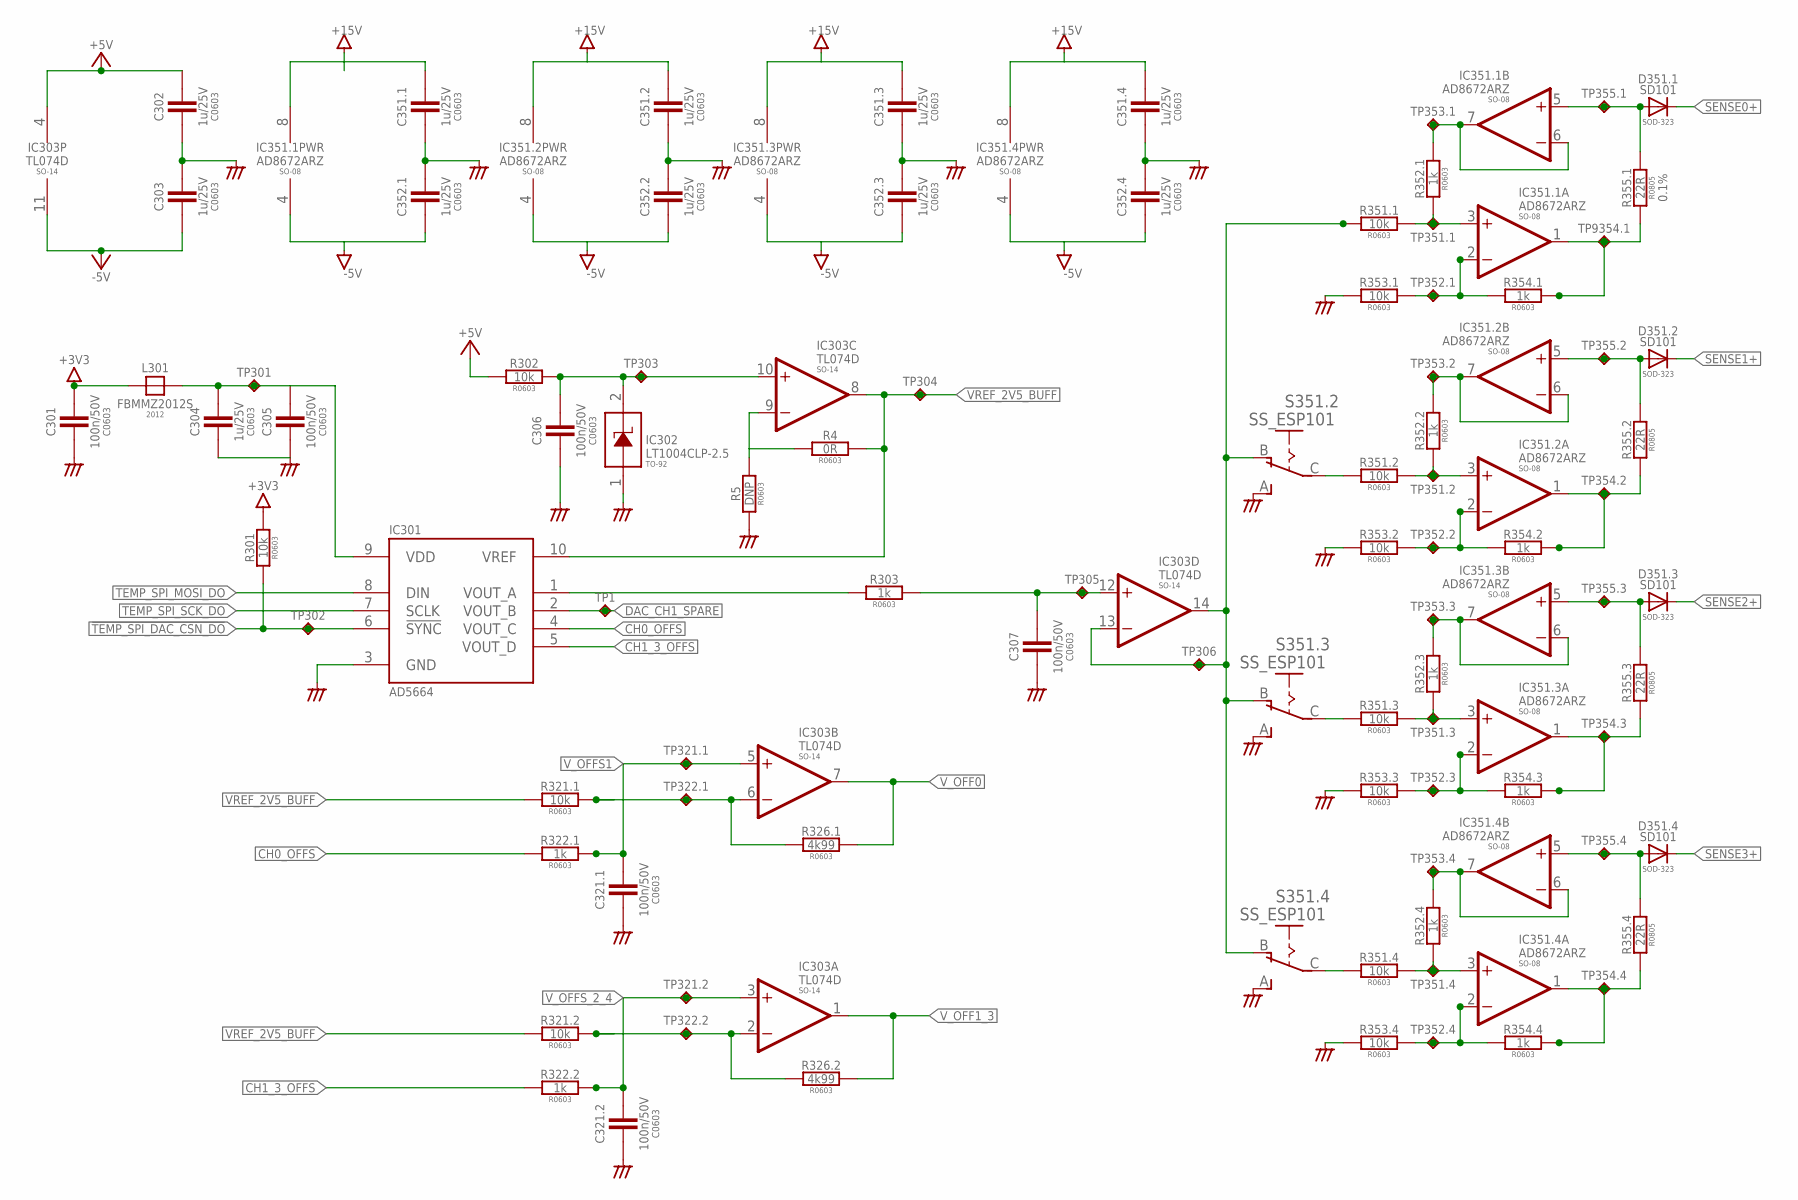
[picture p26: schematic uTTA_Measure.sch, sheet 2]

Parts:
C301, C305, C306, C307, C321.1, C321.2: 100n/50V; C0603
C302, C303, C304, C351.1, C351.2, C351.3, C351.4, C352.1, C352.2, C352.3, C352.4: 1u/25V; C0603
D351.1, D351.2, D351.3, D351.4: SD101; SOD323-R
IC301: AD5664; MSOP10
IC302: LT1004CLP-2.5; TO92-
IC303: TL074D; SO14
IC351.1, IC351.2, IC351.3, IC351.4: AD8672ARZ; SO08
L301: FBMMZ2012S; FB2012
R4: 0R; R0603
R5: DNP; R0603
R301, R302: 10k; R0603
R303, R322.1, R322.2: 1k; R0603
R321.1, R321.2, R351.1, R351.2, R351.3, R351.4, R353.1, R353.2, R353.3, R353.4: 10k; R0603; TOLERANCE 0.1%
R326.1, R326.2: 4k99; R0603; TOLERANCE 0.1%
R352.1, R352.2, R352.3, R352.4, R354.1, R354.2, R354.3, R354.4: 1k; R0603; TOLERANCE 0.1%
R355.1, R355.2, R355.3, R355.4: 22R; R0805; TOLERANCE 0.1%
S351.2, S351.3, S351.4: SS_ESP101
TP1, TP301, TP302, TP304, TP306, TP321.1, TP321.2, TP322.1, TP322.2, TP351.1, TP351.2, TP351.3, TP351.4, TP352.1, TP352.2, TP352.3, TP352.4, TP353.1, TP353.2, TP353.3, TP353.4, TP354.2, TP354.3, TP354.4, TP355.1, TP355.2, TP355.3, TP355.4, TP9354.1: TPC90; C90
TP303, TP305: TPC90H30; C90H30

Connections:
3V3_DAC: C304.1, C305.1, IC301.9 (VDD), L301.2, TP301.P$1
!TEMP_SPI_DAC_CSN_DO: IC301.6 (!SYNC), R301.2, TP302.P$1; also elsewhere on the board
+3V3: C301.1, L301.1, R301.1; also elsewhere on the board
+5V: C302.1, IC303.4 (V+), R302.1; also elsewhere on the board
+15V: C351.1.1, C351.2.1, C351.3.1, C351.4.1, IC351.1.8 (V+), IC351.2.8 (V+), IC351.3.8 (V+), IC351.4.8 (V+); also elsewhere on the board
-5V: C303.2, C352.1.2, C352.2.2, C352.3.2, C352.4.2, IC303.11 (V-), IC351.1.4 (V-), IC351.2.4 (V-), IC351.3.4 (V-), IC351.4.4 (V-); also elsewhere on the board
AGND: C301.2, C302.2, C303.1, C304.2, C305.2, C306.2, C307.2, C321.1.2, C321.2.2, C351.1.2, C351.2.2, C351.3.2, C351.4.2, C352.1.1, C352.2.1, C352.3.1, C352.4.1, IC301.3 (GND), IC302.1 (A), R5.2, R353.1.1, R353.2.1, R353.3.1, R353.4.1, S351.2.A (S), S351.3.A (S), S351.4.A (S); also elsewhere on the board
CH0_OFFS: IC301.4 (VOUT_C), R322.1.1
CH1_3_OFFS: IC301.5 (VOUT_D), R322.2.1
DAC_CH1_SPARE: IC301.2 (VOUT_B), TP1.P$1
ISENS_SET: IC303.13 (-IN), IC303.14 (OUT), R351.1.1, S351.2.B (O), S351.3.B (O), S351.4.B (O), TP306.P$1
ISENS_SET_IN: C307.1, IC303.12 (+IN), R303.2, TP305.P$1
ISEN_FB1: D351.1.A, IC351.1.5 (+IN), R355.1.2, TP355.1.P$1
ISEN_FB2: D351.2.A, IC351.2.5 (+IN), R355.2.2, TP355.2.P$1
ISEN_FB3: D351.3.A, IC351.3.5 (+IN), R355.3.2, TP355.3.P$1
ISEN_FB4: D351.4.A, IC351.4.5 (+IN), R355.4.2, TP355.4.P$1
ISEN_FB_OUT1: IC351.1.6 (-IN), IC351.1.7 (OUT), R352.1.2, TP353.1.P$1
ISEN_FB_OUT2: IC351.2.6 (-IN), IC351.2.7 (OUT), R352.2.2, TP353.2.P$1
ISEN_FB_OUT3: IC351.3.6 (-IN), IC351.3.7 (OUT), R352.3.2, TP353.3.P$1
ISEN_FB_OUT4: IC351.4.6 (-IN), IC351.4.7 (OUT), R352.4.2, TP353.4.P$1
ISEN_FB_SUM1: IC351.1.2 (-IN), R353.1.2, R354.1.1, TP352.1.P$1
ISEN_FB_SUM2: IC351.2.2 (-IN), R353.2.2, R354.2.1, TP352.2.P$1
ISEN_FB_SUM3: IC351.3.2 (-IN), R353.3.2, R354.3.1, TP352.3.P$1
ISEN_FB_SUM4: IC351.4.2 (-IN), R353.4.2, R354.4.1, TP352.4.P$1
ISEN_OUT1: IC351.1.1 (OUT), R354.1.2, R355.1.1, TP9354.1.P$1
ISEN_OUT2: IC351.2.1 (OUT), R354.2.2, R355.2.1, TP354.2.P$1
ISEN_OUT3: IC351.3.1 (OUT), R354.3.2, R355.3.1, TP354.3.P$1
ISEN_OUT4: IC351.4.1 (OUT), R354.4.2, R355.4.1, TP354.4.P$1
ISEN_SET2: R351.2.1, S351.2.C
ISEN_SET3: R351.3.1, S351.3.C
ISEN_SET4: R351.4.1, S351.4.C
ISEN_SET_SUM1: IC351.1.3 (+IN), R351.1.2, R352.1.1, TP351.1.P$1
ISEN_SET_SUM2: IC351.2.3 (+IN), R351.2.2, R352.2.1, TP351.2.P$1
ISEN_SET_SUM3: IC351.3.3 (+IN), R351.3.2, R352.3.1, TP351.3.P$1
ISEN_SET_SUM4: IC351.4.3 (+IN), R351.4.2, R352.4.1, TP351.4.P$1
I_SENSE_DAC_SET: IC301.1 (VOUT_A), R303.1
unnamed: IC303.9 (-IN), R4.2, R5.1
SENSE0+: D351.1.C; also elsewhere on the board
SENSE1+: D351.2.C; also elsewhere on the board
SENSE2+: D351.3.C; also elsewhere on the board
SENSE3+: D351.4.C; also elsewhere on the board
TEMP_SPI_MOSI_DO: IC301.8 (DIN); also elsewhere on the board
TEMP_SPI_SCK_DO: IC301.7 (SCLK); also elsewhere on the board
VOFFS_RR1: IC303.6 (-IN), R321.1.1, R326.1.2, TP322.1.P$1
VOFFS_RR2_4: IC303.2 (-IN), R321.2.1, R326.2.2, TP322.2.P$1
VREF: C306.1, IC302.2 (C), IC303.10 (+IN), R302.2, TP303.P$1
VREF_2V5_BUFF: IC301.10 (VREF), IC303.8 (OUT), R4.1, R321.1.2, R321.2.2, TP304.P$1; also elsewhere on the board
V_OFF0: IC303.7 (OUT), R326.1.1; also elsewhere on the board
V_OFF1_3: IC303.1 (OUT), R326.2.1; also elsewhere on the board
V_OFFS1: C321.1.1, IC303.5 (+IN), R322.1.2, TP321.1.P$1
V_OFFS_2_4: C321.2.1, IC303.3 (+IN), R322.2.2, TP321.2.P$1

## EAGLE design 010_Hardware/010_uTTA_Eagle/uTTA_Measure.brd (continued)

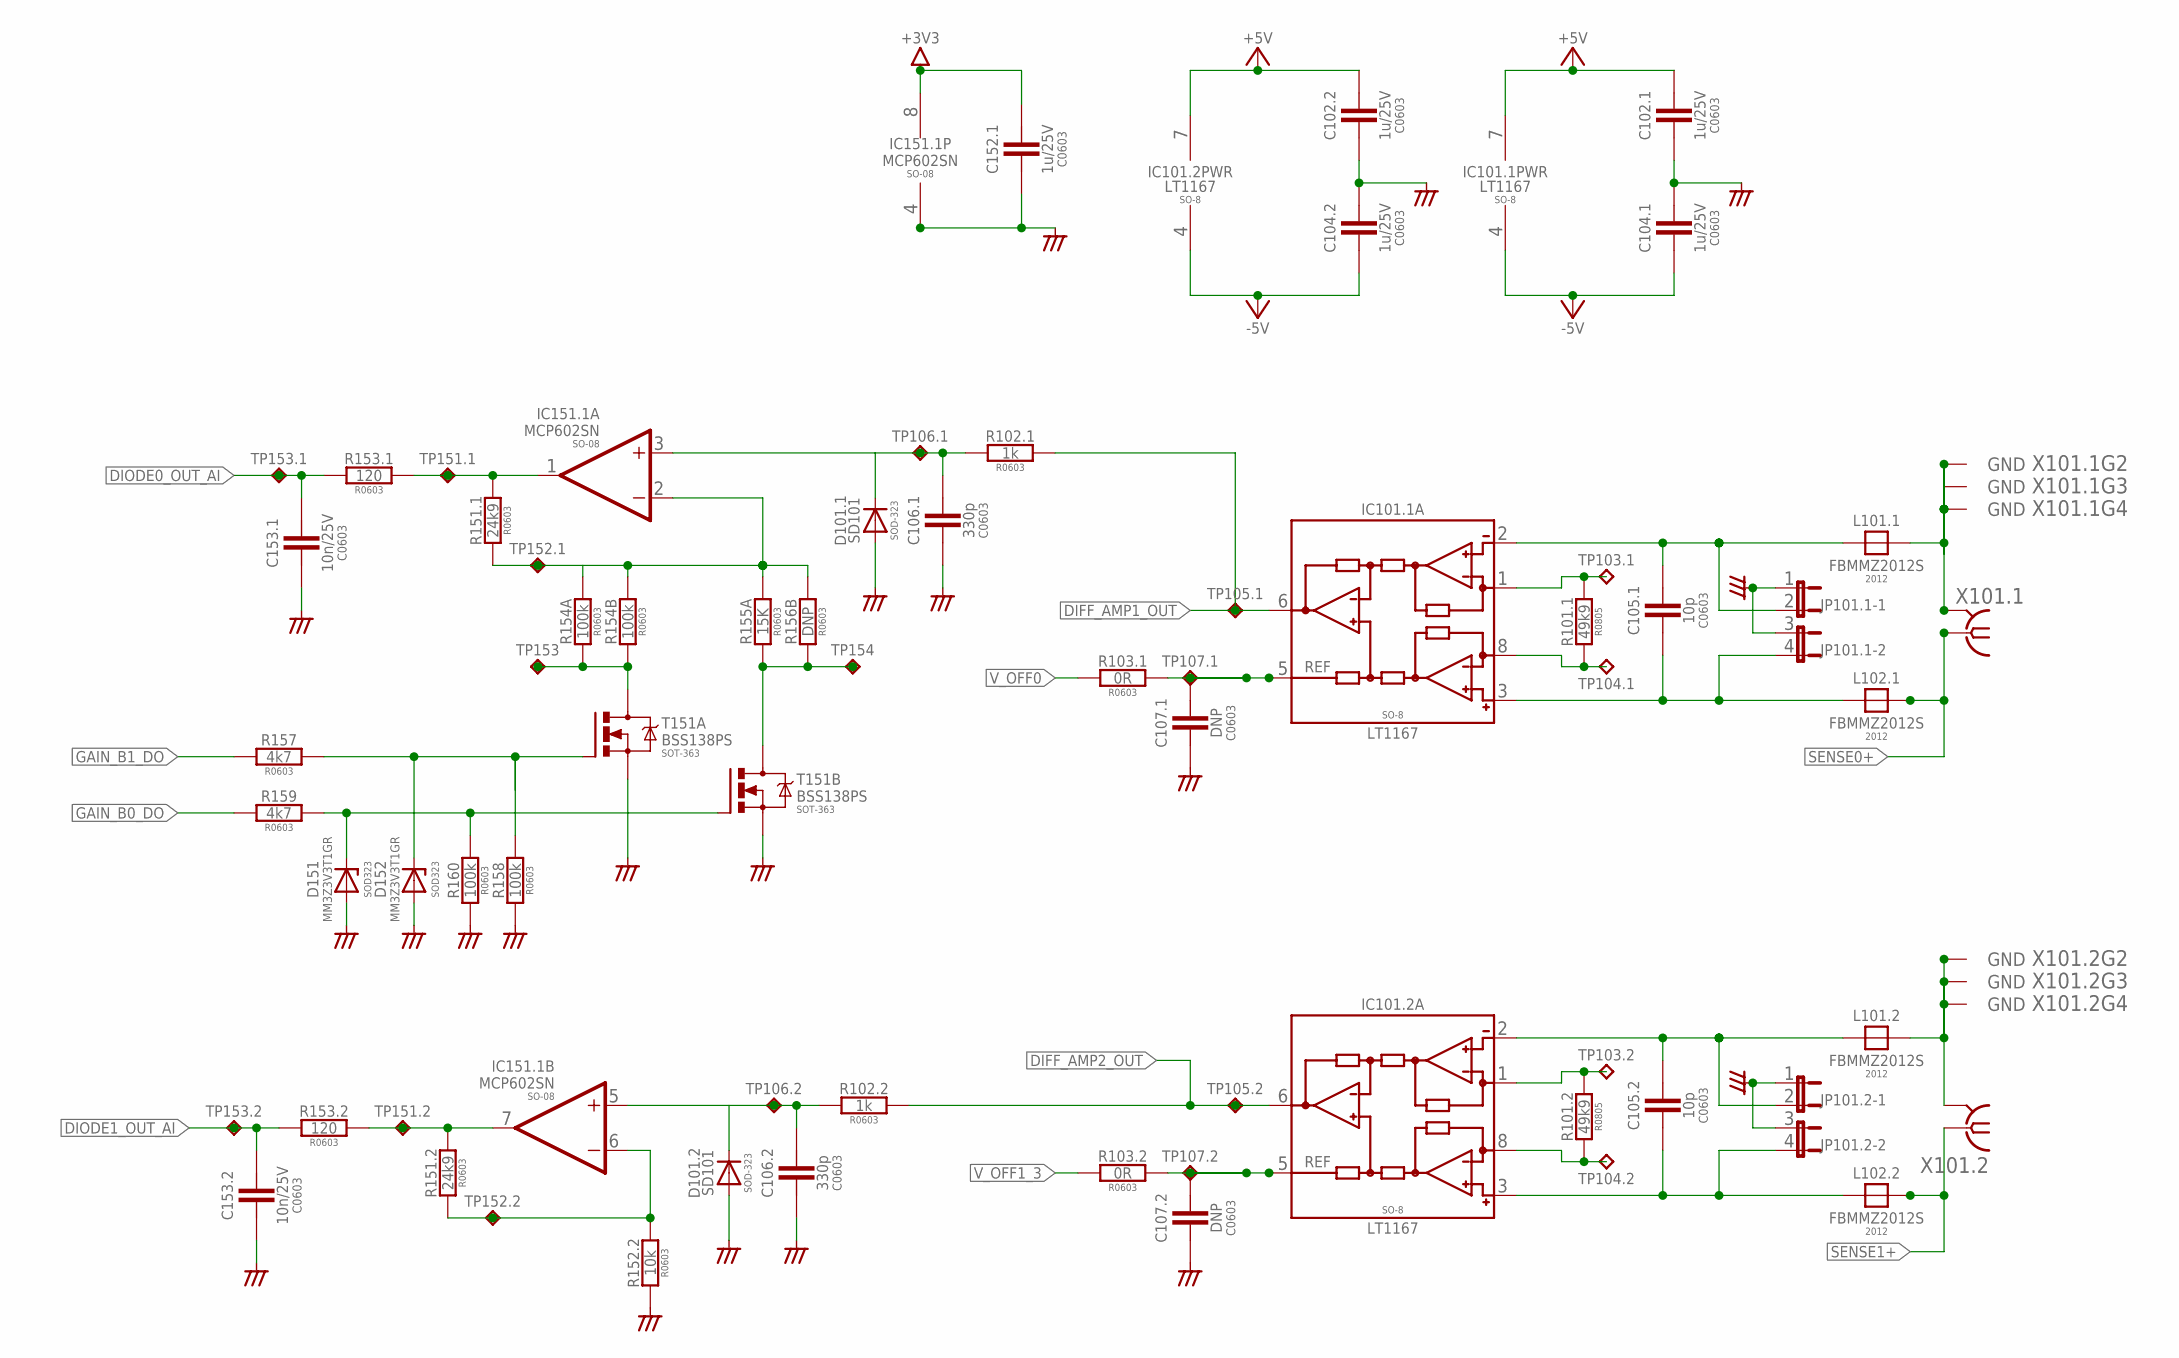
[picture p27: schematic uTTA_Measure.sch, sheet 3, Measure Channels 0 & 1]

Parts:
C102.1, C102.2, C104.1, C104.2, C152.1: 1u/25V; C0603
C105.1, C105.2: 10p; C0603
C106.1, C106.2: 330p; C0603
C107.1, C107.2: DNP; C0603
C153.1, C153.2: 10n/25V; C0603
D101.1, D101.2: SD101; SOD323-R
D151, D152: MM3Z3V3T1GR; SOD323-R
IC101.1, IC101.2: LT1167; SO08
IC151.1: MCP602SN; SO08
JP101.1, JP101.2: JP2QE; JP2Q
L101.1, L101.2, L102.1, L102.2: FBMMZ2012S; FB2012
R101.1, R101.2: 49k9; R0805; TOLERANCE 0.1%
R102.1, R102.2: 1k; R0603
R103.1, R103.2: 0R; R0603
R151.1, R151.2: 24k9; R0603; TOLERANCE 0.1%
R152.2: 10k; R0603; TOLERANCE 0.1%
R153.1, R153.2: 120; R0603
R154A, R154B: 100k; R0603; TOLERANCE 0.1%
R155A: 15K; R0603; TOLERANCE 0.1%
R156B: DNP; R0603
R157, R159: 4k7; R0603
R158, R160: 100k; R0603
T151: BSS138PS; SOT363_PHILIPS
TP103.1, TP103.2, TP104.1, TP104.2, TP105.1, TP105.2, TP107.1, TP107.2, TP152.1, TP152.2, TP153, TP154: TPC90; C90
TP106.1, TP106.2, TP151.1, TP151.2, TP153.1, TP153.2: TPC90H30; C90H30
X101.1, X101.2: BU-SMA-GSPECIAL; BU_SMA_3P

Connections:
+3V3: C152.1.1, IC151.1.8 (V+); also elsewhere on the board
+5V: C102.1.1, C102.2.1, IC101.1.7 (V+), IC101.2.7 (V+); also elsewhere on the board
-5V: C104.1.2, C104.2.2, IC101.1.4 (V-), IC101.2.4 (V-); also elsewhere on the board
AGND: C102.1.2, C102.2.2, C104.1.1, C104.2.1, C106.1.2, C106.2.2, C107.1.2, C107.2.2, C152.1.2, C153.1.2, C153.2.2, D101.1.A, D101.2.A, D151.A, D152.A, IC151.1.4 (V-), JP101.1.1, JP101.1.3 (1), JP101.2.1, JP101.2.3 (1), R152.2.1, R158.1, R160.1, T151.1 (S), T151.4 (S); also elsewhere on the board
AMP1_OUT: IC151.1.1 (OUT), R151.1.2, R153.1.2, TP151.1.P$1
AMP1_RG_B0: R155A.1, R156B.1, T151.6 (D), TP154.P$1
AMP1_RG_B1: R154A.1, R154B.1, T151.3 (D), TP153.P$1
AMP2_FB: IC151.1.6 (-IN), R151.2.1, R152.2.2, TP152.2.P$1
AMP2_OUT: IC151.1.7 (OUT), R151.2.2, R153.2.2, TP151.2.P$1
B0_GATE: D151.C, R159.2, R160.2, T151.5 (G)
B1_GATE: D152.C, R157.2, R158.2, T151.2 (G)
DIFF_AMP1_OUT: IC101.1.6 (OUT), R102.1.2, TP105.1.P$1
DIFF_AMP2_OUT: IC101.2.6 (OUT), R102.2.2, TP105.2.P$1
DIODE0_OUT_AI: C153.1.1, R153.1.1, TP153.1.P$1; also elsewhere on the board
DIODE1_OUT_AI: C153.2.1, R153.2.1, TP153.2.P$1; also elsewhere on the board
DIODE2_IN: C106.2.1, D101.2.C, IC151.1.5 (+IN), R102.2.1, TP106.2.P$1
GAIN1+: IC101.1.8 (RG), R101.1.2, TP104.1.P$1
GAIN1-: IC101.1.1 (RG), R101.1.1, TP103.1.P$1
GAIN2+: IC101.2.8 (RG), R101.2.2, TP104.2.P$1
GAIN2-: IC101.2.1 (RG), R101.2.1, TP103.2.P$1
GAIN_B0_DO: R159.1; also elsewhere on the board
GAIN_B1_DO: R157.1; also elsewhere on the board
IN1+: C105.1.2, IC101.1.3 (+IN), JP101.1.4 (2), L102.1.1
IN1-: C105.1.1, IC101.1.2 (-IN), JP101.1.2, L101.1.1
IN2+: C105.2.2, IC101.2.3 (+IN), JP101.2.4 (2), L102.2.1
IN2-: C105.2.1, IC101.2.2 (-IN), JP101.2.2, L101.2.1
PGA_DIODE1_IN: C106.1.1, D101.1.C, IC151.1.3 (+IN), R102.1.1, TP106.1.P$1
SENSE0+: L102.1.2, X101.1.C1 (1), X101.1.C2 (1); also elsewhere on the board
SENSE1+: L102.2.2, X101.2.C1 (1), X101.2.C2 (1); also elsewhere on the board
SENSE1-: L101.1.2, X101.1.@GND1 (GND), X101.1.@GND2 (GND), X101.1.@GND3 (GND), X101.1.@GND4 (GND), X101.1.GND
SENSE2-: L101.2.2, X101.2.@GND1 (GND), X101.2.@GND2 (GND), X101.2.@GND3 (GND), X101.2.@GND4 (GND), X101.2.GND
TP152.1: IC151.1.2 (-IN), R151.1.1, R154A.2, R154B.2, R155A.2, R156B.2, TP152.1.P$1
V_OFF0: R103.1.1; also elsewhere on the board
V_OFF1_3: R103.2.1; also elsewhere on the board
V_OPREF1: C107.1.1, IC101.1.5 (REF), R103.1.2, TP107.1.P$1
V_OPREF2: C107.2.1, IC101.2.5 (REF), R103.2.2, TP107.2.P$1

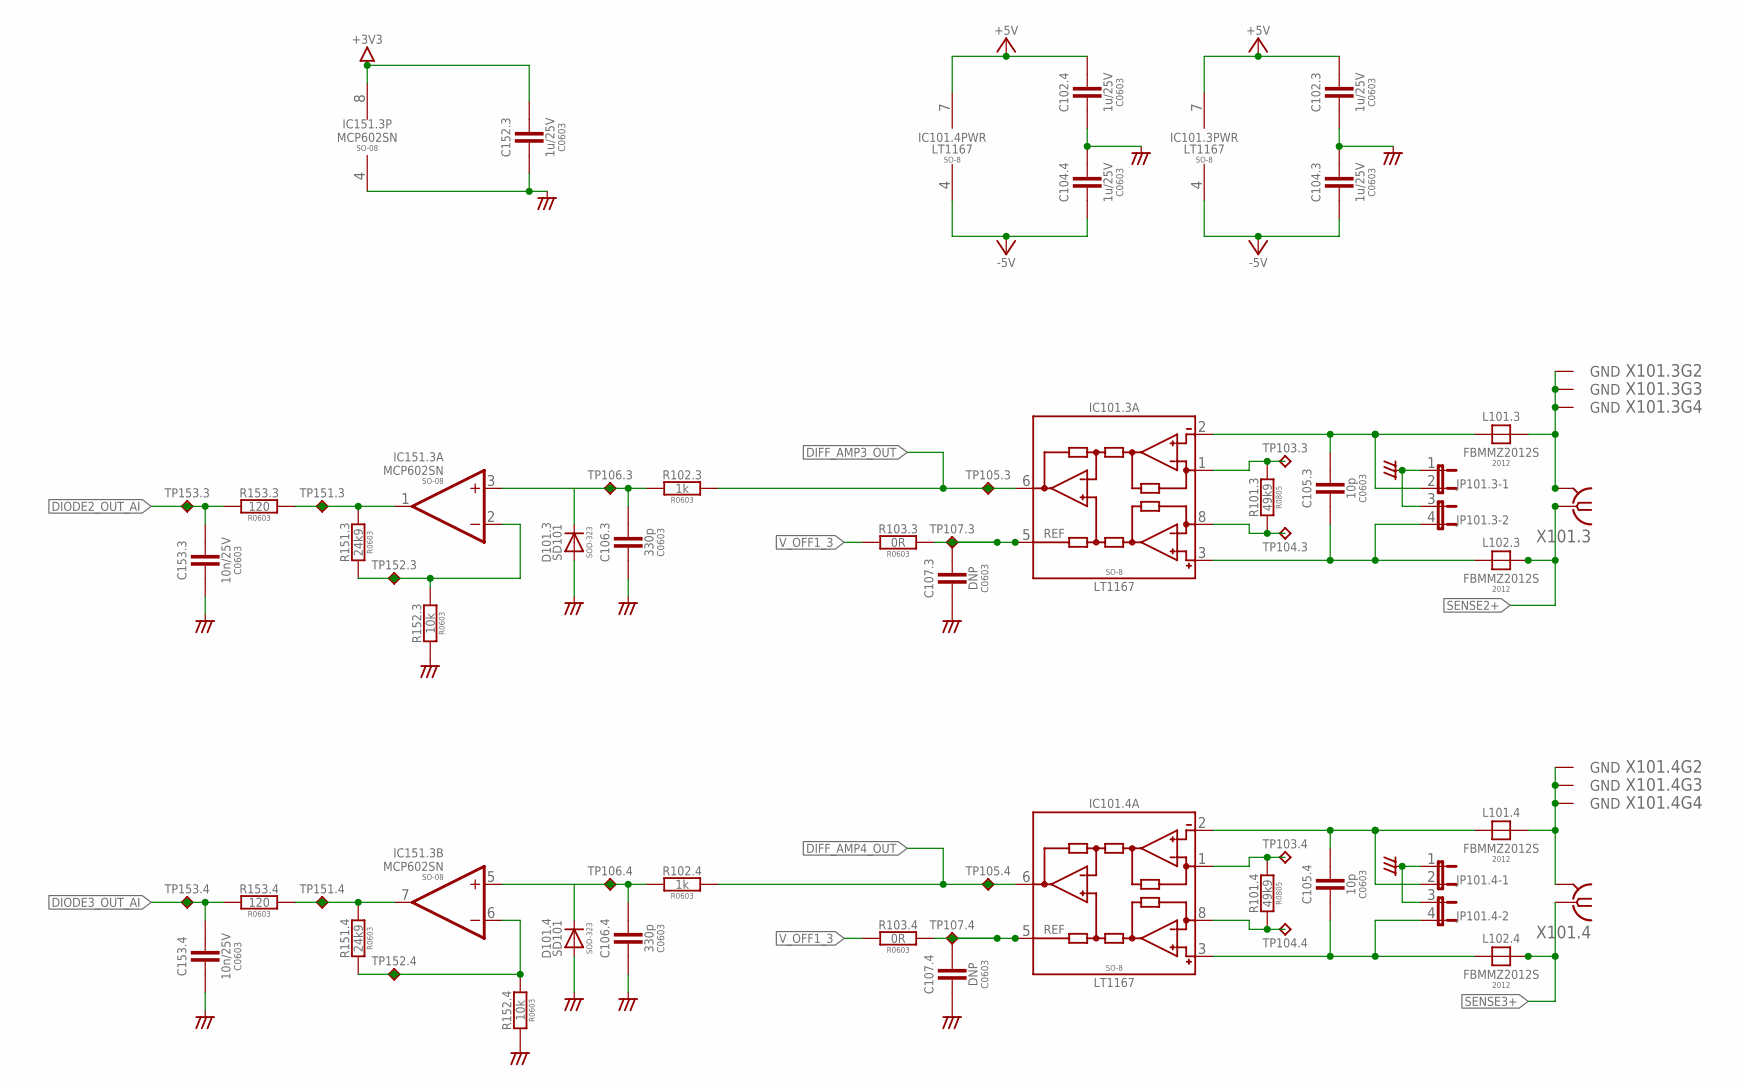
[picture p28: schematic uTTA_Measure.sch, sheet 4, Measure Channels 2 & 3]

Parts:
C102.3, C102.4, C104.3, C104.4, C152.3: 1u/25V; C0603
C105.3, C105.4: 10p; C0603
C106.3, C106.4: 330p; C0603
C107.3, C107.4: DNP; C0603
C153.3, C153.4: 10n/25V; C0603
D101.3, D101.4: SD101; SOD323-R
IC101.3, IC101.4: LT1167; SO08
IC151.3: MCP602SN; SO08
JP101.3, JP101.4: JP2QE; JP2Q
L101.3, L101.4, L102.3, L102.4: FBMMZ2012S; FB2012
R101.3, R101.4: 49k9; R0805; TOLERANCE 0.1%
R102.3, R102.4: 1k; R0603
R103.3, R103.4: 0R; R0603
R151.3, R151.4: 24k9; R0603; TOLERANCE 0.1%
R152.3, R152.4: 10k; R0603; TOLERANCE 0.1%
R153.3, R153.4: 120; R0603
TP103.3, TP103.4, TP104.3, TP104.4, TP105.3, TP105.4, TP107.3, TP107.4: TPC90; C90
TP106.3, TP106.4, TP151.3, TP151.4, TP152.3, TP152.4, TP153.3, TP153.4: TPC90H30; C90H30
X101.3, X101.4: BU-SMA-GSPECIAL; BU_SMA_3P

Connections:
+3V3: C152.3.1, IC151.3.8 (V+); also elsewhere on the board
+5V: C102.3.1, C102.4.1, IC101.3.7 (V+), IC101.4.7 (V+); also elsewhere on the board
-5V: C104.3.2, C104.4.2, IC101.3.4 (V-), IC101.4.4 (V-); also elsewhere on the board
AGND: C102.3.2, C102.4.2, C104.3.1, C104.4.1, C106.3.2, C106.4.2, C107.3.2, C107.4.2, C152.3.2, C153.3.2, C153.4.2, D101.3.A, D101.4.A, IC151.3.4 (V-), JP101.3.1, JP101.3.3 (1), JP101.4.1, JP101.4.3 (1), R152.3.1, R152.4.1; also elsewhere on the board
AMP3_FB: IC151.3.2 (-IN), R151.3.1, R152.3.2, TP152.3.P$1
AMP3_OUT: IC151.3.1 (OUT), R151.3.2, R153.3.2, TP151.3.P$1
AMP4_FB: IC151.3.6 (-IN), R151.4.1, R152.4.2, TP152.4.P$1
AMP4_OUT: IC151.3.7 (OUT), R151.4.2, R153.4.2, TP151.4.P$1
DIFF_AMP3_OUT: IC101.3.6 (OUT), R102.3.2, TP105.3.P$1
DIFF_AMP4_OUT: IC101.4.6 (OUT), R102.4.2, TP105.4.P$1
DIODE2_OUT_AI: C153.3.1, R153.3.1, TP153.3.P$1; also elsewhere on the board
DIODE3_IN: C106.3.1, D101.3.C, IC151.3.3 (+IN), R102.3.1, TP106.3.P$1
DIODE3_OUT_AI: C153.4.1, R153.4.1, TP153.4.P$1; also elsewhere on the board
DIODE4_IN: C106.4.1, D101.4.C, IC151.3.5 (+IN), R102.4.1, TP106.4.P$1
GAIN3+: IC101.3.8 (RG), R101.3.2, TP104.3.P$1
GAIN3-: IC101.3.1 (RG), R101.3.1, TP103.3.P$1
GAIN4+: IC101.4.8 (RG), R101.4.2, TP104.4.P$1
GAIN4-: IC101.4.1 (RG), R101.4.1, TP103.4.P$1
IN3+: C105.3.2, IC101.3.3 (+IN), JP101.3.4 (2), L102.3.1
IN3-: C105.3.1, IC101.3.2 (-IN), JP101.3.2, L101.3.1
IN4+: C105.4.2, IC101.4.3 (+IN), JP101.4.4 (2), L102.4.1
IN4-: C105.4.1, IC101.4.2 (-IN), JP101.4.2, L101.4.1
SENSE2+: L102.3.2, X101.3.C1 (1), X101.3.C2 (1); also elsewhere on the board
SENSE3+: L102.4.2, X101.4.C1 (1), X101.4.C2 (1); also elsewhere on the board
SENSE3-: L101.3.2, X101.3.@GND1 (GND), X101.3.@GND2 (GND), X101.3.@GND3 (GND), X101.3.@GND4 (GND), X101.3.GND
SENSE4-: L101.4.2, X101.4.@GND1 (GND), X101.4.@GND2 (GND), X101.4.@GND3 (GND), X101.4.@GND4 (GND), X101.4.GND
V_OFF1_3: R103.3.1, R103.4.1; also elsewhere on the board
V_OPREF3: C107.3.1, IC101.3.5 (REF), R103.3.2, TP107.3.P$1
V_OPREF4: C107.4.1, IC101.4.5 (REF), R103.4.2, TP107.4.P$1

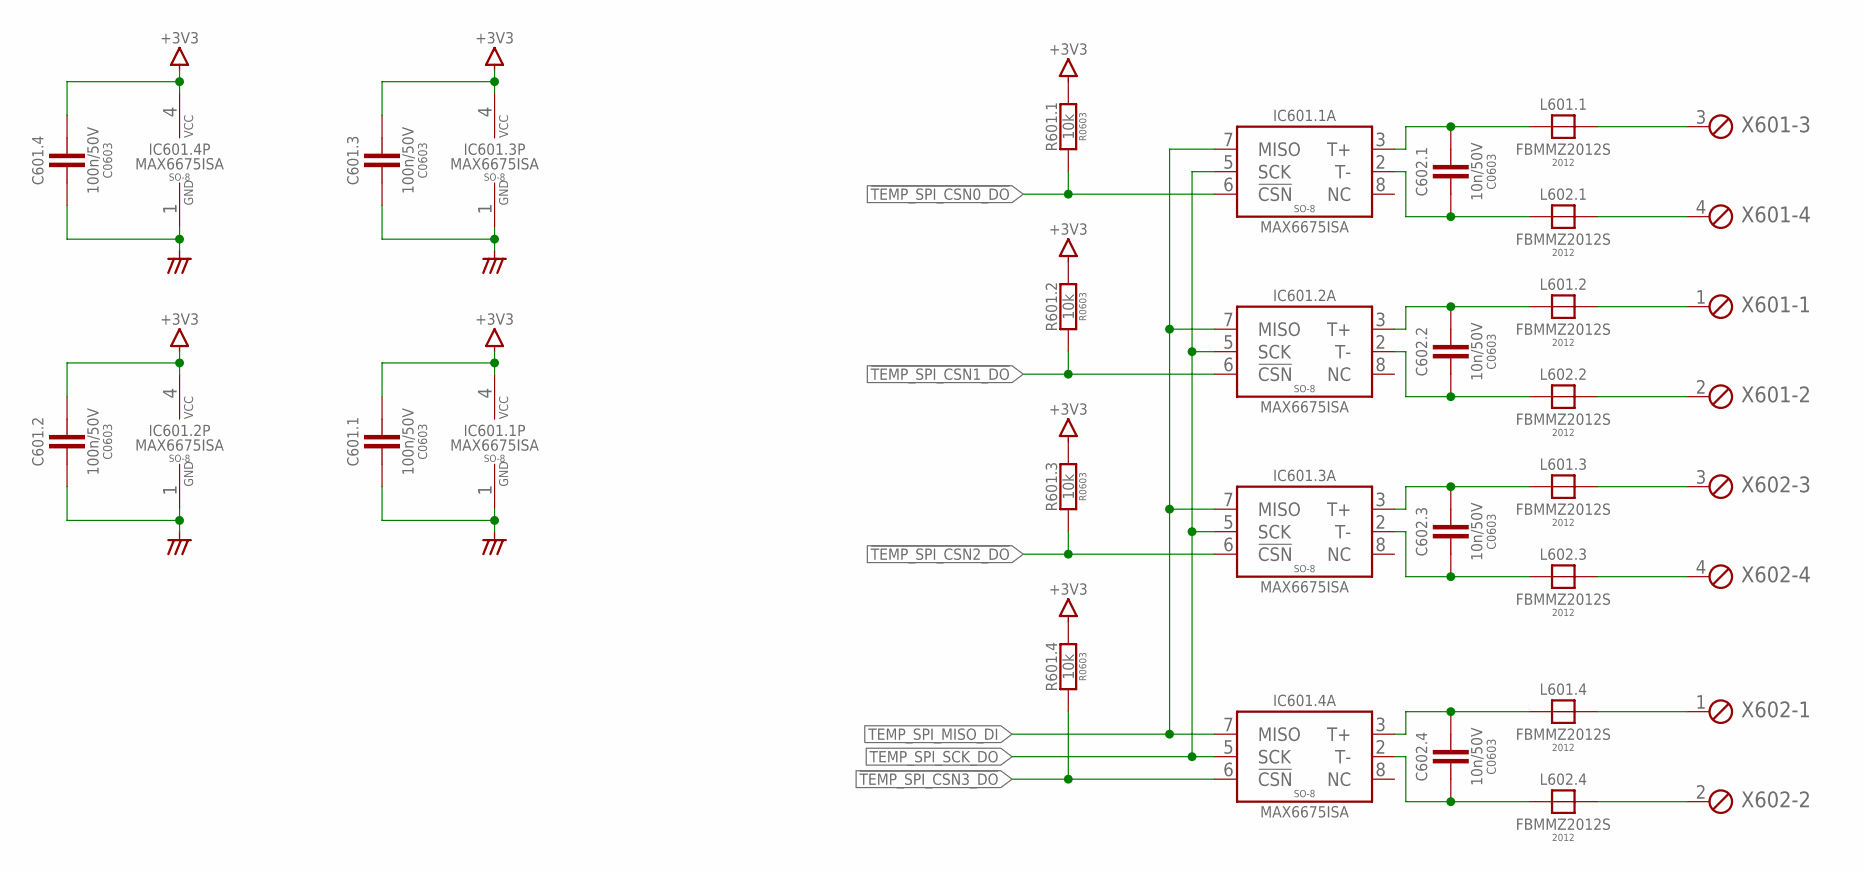
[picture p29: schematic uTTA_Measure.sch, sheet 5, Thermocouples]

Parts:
C601.1, C601.2, C601.3, C601.4: 100n/50V; C0603
C602.1, C602.2, C602.3, C602.4: 10n/50V; C0603
IC601.1, IC601.2, IC601.3, IC601.4: MAX6675ISA; SO08
L601.1, L601.2, L601.3, L601.4, L602.1, L602.2, L602.3, L602.4: FBMMZ2012S; FB2012
R601.1, R601.2, R601.3, R601.4: 10k; R0603
X601, X602: MPT4; 4POL254

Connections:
!TEMP_SPI_CSN0_DO: IC601.1.6 (!CSN), R601.1.2; also elsewhere on the board
!TEMP_SPI_CSN1_DO: IC601.2.6 (!CSN), R601.2.2; also elsewhere on the board
!TEMP_SPI_CSN2_DO: IC601.3.6 (!CSN), R601.3.2; also elsewhere on the board
!TEMP_SPI_CSN3_DO: IC601.4.6 (!CSN), R601.4.2; also elsewhere on the board
+3V3: C601.1.1, C601.2.1, C601.3.1, C601.4.1, IC601.1.4 (VCC), IC601.2.4 (VCC), IC601.3.4 (VCC), IC601.4.4 (VCC), R601.1.1, R601.2.1, R601.3.1, R601.4.1; also elsewhere on the board
AGND: C601.1.2, C601.2.2, C601.3.2, C601.4.2, IC601.1.1 (GND), IC601.2.1 (GND), IC601.3.1 (GND), IC601.4.1 (GND); also elsewhere on the board
TC1+: L601.4.2, X602.1
TC1-: L602.4.2, X602.2
TC2+: L601.3.2, X602.3
TC2-: L602.3.2, X602.4
TC3+: L601.2.2, X601.1
TC3-: L602.2.2, X601.2
TC4+: L601.1.2, X601.3
TC4-: L602.1.2, X601.4
TEMP_SPI_MISO_DI: IC601.1.7 (MISO), IC601.2.7 (MISO), IC601.3.7 (MISO), IC601.4.7 (MISO); also elsewhere on the board
TEMP_SPI_SCK_DO: IC601.1.5 (SCK), IC601.2.5 (SCK), IC601.3.5 (SCK), IC601.4.5 (SCK); also elsewhere on the board
TK1_N: C602.4.2, IC601.4.2 (T-), L602.4.1
TK1_P: C602.4.1, IC601.4.3 (T+), L601.4.1
TK2_N: C602.3.2, IC601.3.2 (T-), L602.3.1
TK2_P: C602.3.1, IC601.3.3 (T+), L601.3.1
TK3_N: C602.2.2, IC601.2.2 (T-), L602.2.1
TK3_P: C602.2.1, IC601.2.3 (T+), L601.2.1
TK4_N: C602.1.2, IC601.1.2 (T-), L602.1.1
TK4_P: C602.1.1, IC601.1.3 (T+), L601.1.1

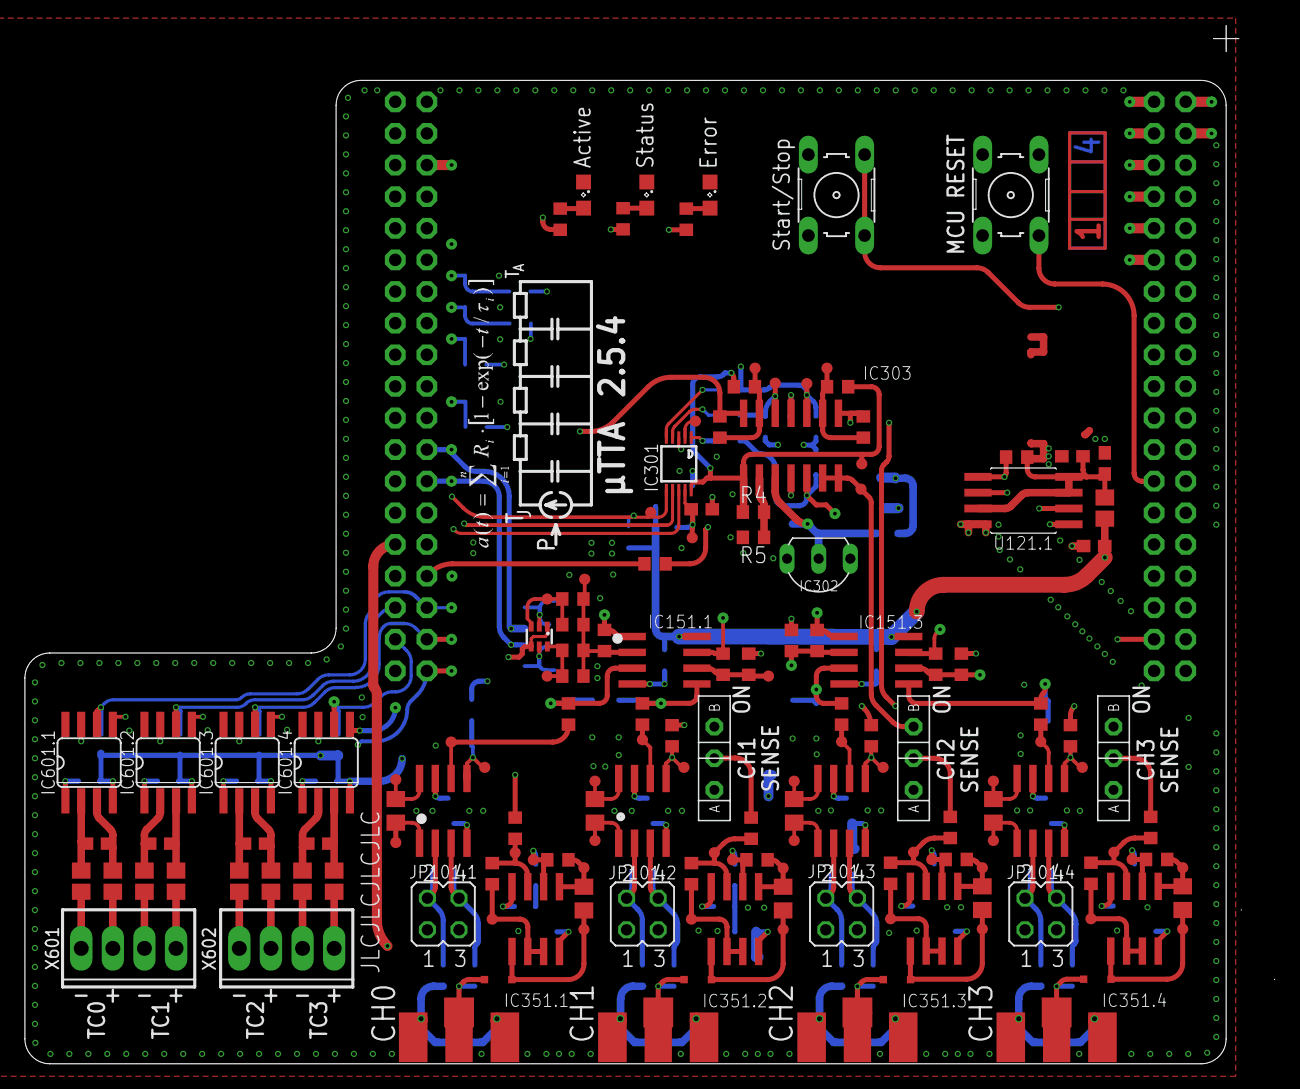
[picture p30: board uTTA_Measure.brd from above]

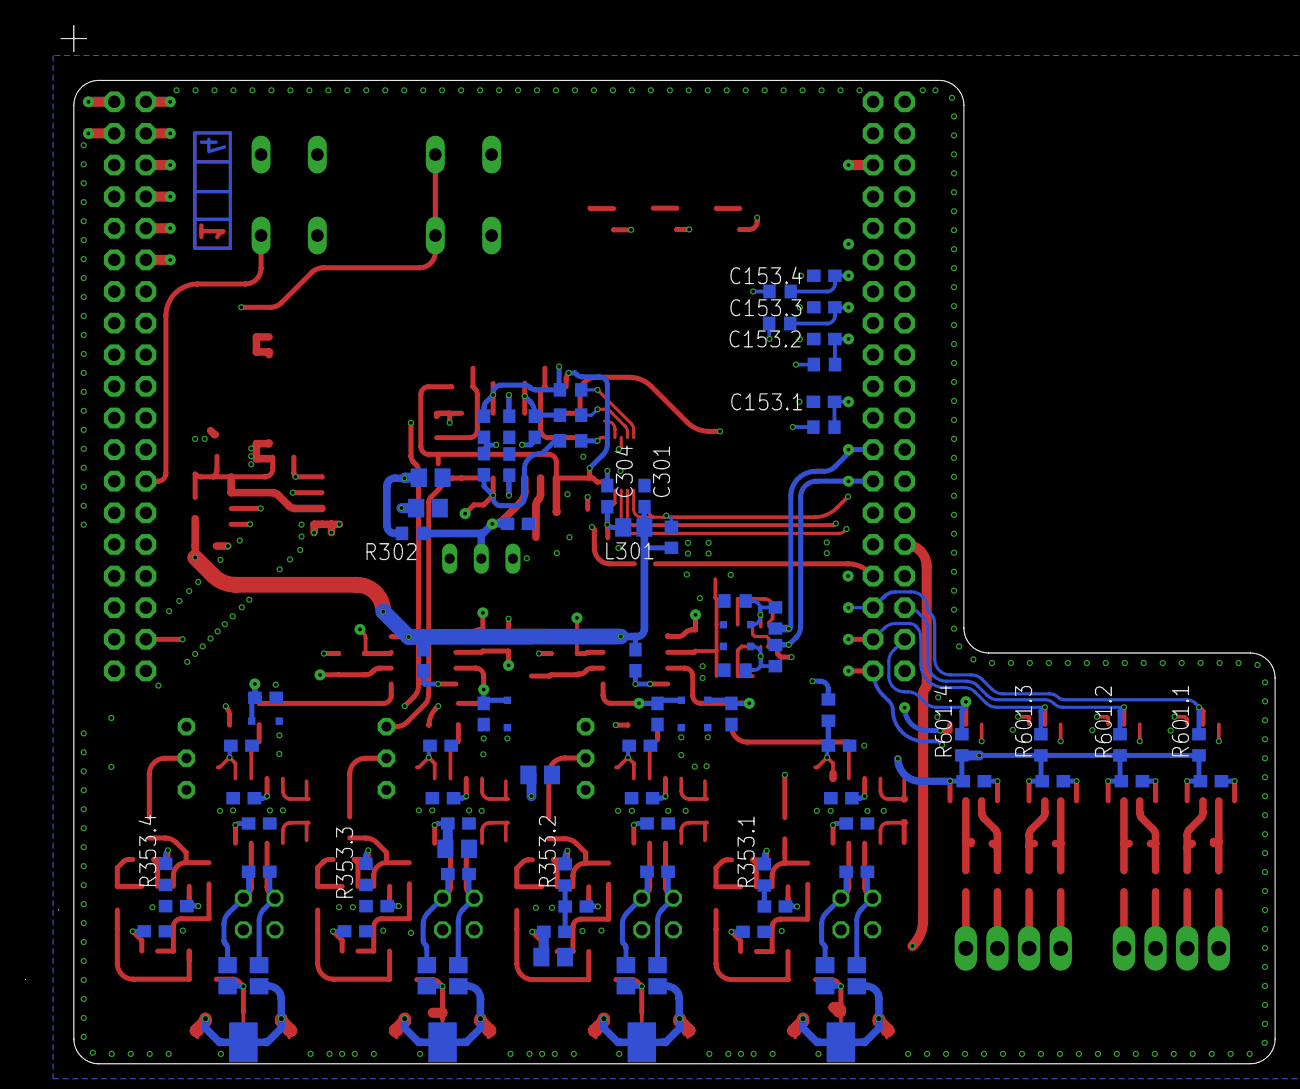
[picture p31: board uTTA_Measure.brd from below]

Board: 4 copper layers, 100.4 x 83.4 mm, 280 parts (88 on the bottom side), 145 nets.

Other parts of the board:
U$1: A4_LOC_CC_BY_NC_SA

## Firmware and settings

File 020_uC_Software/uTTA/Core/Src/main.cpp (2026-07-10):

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
/* Includes ------------------------------------------------------------------*/
#include <main.hpp>
#include "Vrekrer_scpi_parser.hpp"
#include "MAX6675.h"
#include "SCPI_server.h"
#include "dev_cal.h"


W25QXX_HandleTypeDef w25qxx;

lfs_file_t file;
lfs_t littlefs;

char LogWriteBfr[TX_BFR_SIZE];
uint32_t ADC_Buffer12[ADC_BFR_BLOCKS*ADC_BFR_SIZE] __attribute__((aligned (4)));
uint32_t ADC_Buffer34[ADC_BFR_BLOCKS*ADC_BFR_SIZE] __attribute__((aligned (4)));

volatile uint8_t ADC_PGA_Setting[ADC_BFR_BLOCKS];
volatile int32_t ADC_TotalBlocks = 0;
volatile int32_t ADC_CoolingStartBlock = 0;
PGA_t PGA_Gains = {PGA_DEF_GAIN, PGA_DEF_GAIN, PGA_DEF_GAIN};
volatile Timing_t SamplingTiming = {ADC_DEF_SAMPLETIME, 0.0f, ADC_MAX_MULTIPLIER, ADC_MAX_SAMPLERATE << ADC_MAX_MULTIPLIER, ADC_MAX_MULTIPLIER, MEAS_DEF_PREHEATING_TIME, MEAS_DEF_HEATING_TIME, MEAS_DEF_COOLING_TIME, TEST_DEF_SAMPLE_TIME};


uint32_t Meas_RunTime = 0;
uint8_t Error_BlinkCtr = 0;
uint32_t Meas_StartTime = 0;
float Temp_TypeK[MAX6675_DEVICES];
int GlobalWriteErrorFlag = 0;
int FlashMemoryAvailable = 0;

volatile MeasurementStates_t FlagMeasurementState = Meas_State_Idle;

DeviceModes_t OperatingMode = Mode_Normal;
char DUT_Name[MAX_DUT_NAME_LENGTH] = {"DUT.umf"};

CH_Def Channels[4] = { 	{"Driver"  , 0, -2600, 0},
						{"Monitor1", 0, -2600, 0},
						{"Monitor2", 0, -2600, 0},
						{"Spare"   , 0, -2600, 0}};


char TxBuffer[TX_BFR_SIZE];
extern char RxBuffer_Stat[RX_BFR_SIZE];
extern uint8_t RxBuffer_DMA[RX_BFR_SIZE];


//SCPI Function Prototypes
extern SCPI_Parser my_instrument;


/**************************************************************************/
/*!
  * @brief  The application entry point.
  * @retval int
*/
int main(void)
{
  /* MCU Configuration--------------------------------------------------------*/
  /* Reset of all peripherals, Initializes the Flash interface and the Systick. */
  LL_APB2_GRP1_EnableClock(LL_APB2_GRP1_PERIPH_SYSCFG);
  LL_APB1_GRP1_EnableClock(LL_APB1_GRP1_PERIPH_PWR);

  /* System interrupt init*/
  NVIC_SetPriorityGrouping(NVIC_PRIORITYGROUP_0);

  /* Configure the system clock */
  SystemClock_Config();

  // Initialize the timer for 1 ms intervals
  SysTick_Config(SystemCoreClock/1000);

  //LL_SYSTICK_EnableIT();
  LL_mDelay(500);

  /* Initialize all configured peripherals */
  MX_GPIO_Init();
  MX_RTC_Init();
  MX_DMA_Init();
  MX_USART2_UART_Init();
  MX_ADC3_Init();
  MX_ADC4_Init();
  MX_SPI3_Init();
  MX_TIM1_Init();
  MX_ADC1_Init();
  MX_ADC2_Init();

  Init_MAX6675();

  RTC_DateTypeDef StartupDate;
  RTC_read_date(&StartupDate);
  if(StartupDate.RTC_Year == 0){
	  RTC_write_date_fmt(BUILD_YEAR ,BUILD_MONTH, BUILD_DAY, 1);
	  RTC_write_time_fmt(BUILD_HOUR, BUILD_MIN, BUILD_SEC);
  }

  Enable_ADC_Clock();

  LL_GPIO_ResetOutputPin(PSU_EN_DO_GPIO_Port, PSU_EN_DO_Pin);
  LL_GPIO_ResetOutputPin(PWSTG_EN_DO_GPIO_Port, PWSTG_EN_DO_Pin);

  // needs some tweaking to get the hashes free from overlaps and collisions
  my_instrument.hash_magic_number = 53; //Default value = 37
  my_instrument.hash_magic_offset = 3;  //Default value = 7
  Init_SCPI_server();

  my_instrument.PrintDebugInfo(USART2, 0);

  uint32_t TotalMem=0;

  if (w25qxx_init(&w25qxx, SPI3, FLASH_SPI_CS_GPIO_Port, FLASH_SPI_CS_Pin) == W25QXX_Ok) {
	  INIT_DBG("Manufacturer       = 0x%2x\n", w25qxx.manufacturer_id);
	  INIT_DBG("Device             = 0x%4x\n", w25qxx.device_id);
	  INIT_DBG("Block size         = 0x%04x (%lu)\n", w25qxx.block_size, w25qxx.block_size);
	  INIT_DBG("Block count        = 0x%04x (%lu)\n", w25qxx.block_count, w25qxx.block_count);
	  INIT_DBG("Total size (in kB) = 0x%04x (%lu)\n", (w25qxx.block_count * w25qxx.block_size) / 1024, (w25qxx.block_count * w25qxx.block_size) / 1024);

	  EvalLFSError(w25qxx_littlefs_init(&w25qxx));

	  lfs_mem_size(&littlefs, "/", &TotalMem);
	  DBG_LVL1("Total size used memory = %lu bytes\n", TotalMem);
	  uint32_t lfs_used_bytes =  lfs_fs_size(&littlefs)*0xffff;
	  DBG_LVL1("Total size used blocks = %lu blocks, %lu bytes\n", lfs_fs_size(&littlefs), lfs_used_bytes);

	  Read_CalibrationFromFlash(&littlefs, &file, 0);

	  FlashMemoryAvailable = 1;
  }
  else{
	  ErrorResponse(ERRC_SYSTEM_ERROR, ERST_NO_FLASH_MEMORY);
	  FlashMemoryAvailable = -1;
  }

  AD56x4_Init(&ChannelCalibValues[DAC_Ch_ISEN]);
  AD56x4_SetDefaultOutput();

  UART_printf("RTC Time: ");
  print_RTC_DateTime(0,0);
  UART_printf("\n");

  uint32_t LastTempMeasure = GetTick();

  while (1)
  {

	  char* message = my_instrument.GetMessage(USART2, RxBuffer_Stat,"\n");
	  if (message != NULL) {
		  if(my_instrument.comm_mode == CommMode_SCPI){
			  my_instrument.Execute(message, USART2);
		  }else{
			  FileUpload_SerialToFile(message);
		  }

	  }
	  DoMeasurement();

	  if(GetTick() > LastTempMeasure){		// Measurement is running
		  LastTempMeasure += MEASURE_TEMP_UPDATE_TIME;

		  for(uint8_t TKidx =0 ; TKidx<MAX6675_DEVICES; TKidx++){
			  Temp_TypeK[TKidx] = Read_MAX6675(TKidx);
		  }

		  if(FlagMeasurementState){
			  LL_GPIO_SetOutputPin(ACTIVE_LED_DO_GPIO_Port, ACTIVE_LED_DO_Pin);
			  LL_GPIO_TogglePin(STATUS_LED_DO_GPIO_Port, STATUS_LED_DO_Pin);
		  }
		  else{
			  LL_GPIO_ResetOutputPin(ACTIVE_LED_DO_GPIO_Port, ACTIVE_LED_DO_Pin);
			  LL_GPIO_ResetOutputPin(STATUS_LED_DO_GPIO_Port, STATUS_LED_DO_Pin);
		  }

		  if(ErrorTotalCount > 0){
			  if(Error_BlinkCtr < 2*ErrorTotalCount)
			  {
				  LL_GPIO_TogglePin(ERROR_LED_DO_GPIO_Port, ERROR_LED_DO_Pin);
			  }else{
				  LL_GPIO_ResetOutputPin(ERROR_LED_DO_GPIO_Port, ERROR_LED_DO_Pin);
			  }
			  Error_BlinkCtr++;

			  if(Error_BlinkCtr >= (2*ErrorTotalCount +5)){	// Reset for a new blink sequence
				  Error_BlinkCtr = 0;
			  }
		  }
		  else{	// No Errors, no LED
			  LL_GPIO_ResetOutputPin(ERROR_LED_DO_GPIO_Port, ERROR_LED_DO_Pin);
		  }
	  }


  }
}


/**************************************************************************/
/*!
    @brief  State machine that controls the measurement
    @param none
    @returns none
*/
/**************************************************************************/
void DoMeasurement(void)
{

	static uint32_t MeasurementStartTime;		// holds the start time of the measurement
	static uint32_t MeasurementNextStepTime;	// the time when the next timestep will be done (roughly)
	static uint8_t ADC_BufferReadBlock;
	static int32_t Log_WrittenBlocks;
	static uint32_t NextOutput;
	union ADC_conv adc_val;
	int16_t ADC_BFR_idx;
	bool PrintLastADC=false;
	RTC_TimeTypeDef Time;


	int LFS_ret = 0;

	switch(FlagMeasurementState){
	case Meas_State_Init:					// check for the flag to start the measurement
		ADC_TotalBlocks = 0;
		ADC_CoolingStartBlock = 0;
		ADC_BufferReadBlock = 0;
		Log_WrittenBlocks = 0;

		NextOutput = GetTick();

		if(FlashMemoryAvailable <= 0){	// no flash memory is attached to save measurement data therefore the measurement is aborted
			ErrorResponse(ERRC_FILE_SYSTEM, ERST_NO_FLASH_MEMORY);
			FlagMeasurementState = Meas_State_Idle;
			break;
		}
		if(CalAvailable < 1){		// No valid calibration file was found therefore the measurement is aborted
			ErrorResponse(ERRC_SYSTEM_ERROR, ERST_NO_CALIBRATION);
			FlagMeasurementState = Meas_State_Idle;
			break;
		}
		CheckMemoryFileFit();

		SetPGAGain(PGA_Gains.Cooling);
		for(uint8_t PGA_Idx=0; PGA_Idx<ADC_BFR_BLOCKS; PGA_Idx++){
			ADC_PGA_Setting[PGA_Idx] = PGA_Gains.Set;
		}

		// check if the file already exists, abort the measurement if the file is already there
		LFS_ret = lfs_file_open(&littlefs, &file, DUT_Name, LFS_O_RDONLY);
		if((uint8_t)LFS_ret !=254){
			ErrorResponse(ERRC_FILE_SYSTEM, (uint8_t)LFS_ret);
			FlagMeasurementState = Meas_State_Idle;
			EvalLFSError(lfs_file_close(&littlefs, &file));
			break;
		}
		else{	// Clean the flag after this test
			LFS_ret = 0;
		}

		LL_GPIO_SetOutputPin(PWSTG_PWR_EN_DO_GPIO_Port, PWSTG_PWR_EN_DO_Pin);		// turn on the power of the gate driver

		MeasurementNextStepTime = GetTick() + 20;		// Add a delay of 20ms to allow the gate driver power to settle
		FlagMeasurementState=Meas_State_GDPowerCheck;
		break;
	case Meas_State_GDPowerCheck:
		if(GetTick()< MeasurementNextStepTime) break;

#ifdef EARLY_HW_POWER_BOARD
		if(LL_GPIO_IsInputPinSet(PWSTG_PGOOD_DI_GPIO_Port, PWSTG_PGOOD_DI_Pin))
#else
		if(!LL_GPIO_IsInputPinSet(PWSTG_PGOOD_DI_GPIO_Port, PWSTG_PGOOD_DI_Pin))
#endif
		{
			ErrorResponse(ERRC_SYSTEM_ERROR, ERST_GATEDRV_UVLO);
			FlagMeasurementState = Meas_State_Deinit;
			break;
		}

		FlagMeasurementState = Meas_State_InitMeasFile;	// Set the step for the StateMachine to the next step
		break;
	case Meas_State_InitMeasFile:

		Meas_StartTime = GetTick();

		EvalLFSError(lfs_file_open(&littlefs, &file, DUT_Name, LFS_O_WRONLY | LFS_O_CREAT | LFS_O_TRUNC));
		if(LFS_ret<0){
			ErrorResponse(ERRC_FILE_SYSTEM, (uint8_t)LFS_ret);
			FlagMeasurementState = Meas_State_Idle;
			break;
		}

		WriteFileHeaderToFile(&littlefs, &file);

		MeasurementStartTime = GetTick();	// Calculate the time when the next Measurement step shall be started
		MeasurementNextStepTime = MeasurementStartTime + SamplingTiming.PreHeatingTime;

		Setup_TIM1(TIM_Mode_Normal);

		SamplingTiming.SetMultiplier = SamplingTiming.MaxTimeMultiplier;
		SamplingTiming.SetSampleTime = (SamplingTiming.FastSampleTime << SamplingTiming.SetMultiplier);
		CalcADCSamplingSettings(SamplingTiming.SetSampleTime);

		Init_ADC_DMA(ADC1_DIODE1_PGA_IN_AI_CH, ADC2_DIODE2_IN_AI_CH, ADC3_DIODE2_IN_AI_CH, ADC4_CURRENT_IN_AI_CH,(uint32_t)&ADC_Buffer12, (uint32_t)&ADC_Buffer34);

		ENABLE_TIMER;						// Enable the timer for ADC sample rate generation

		FlagMeasurementState = Meas_State_Preheating;	// Set the step for the StateMachine to the next step
		break;

	case Meas_State_Preheating:

		if(GetTick()< MeasurementNextStepTime) break;

		if( SamplingTiming.HeatingTime > 0){		// check if this is a real measurement or just a calibration run
			LL_GPIO_SetOutputPin(PSU_EN_DO_GPIO_Port, PSU_EN_DO_Pin); // Enable the output of the Main Power Supply
			MeasurementNextStepTime += SamplingTiming.HeatingTime;
			FlagMeasurementState = Meas_State_PrepHeating;
		}else		// Just a calibration measurement
		{
			FlagMeasurementState = Meas_State_Deinit;
			ADC_CoolingStartBlock = -1;
		}
		break;
	case Meas_State_Heating:

#ifdef EARLY_HW_POWER_BOARD
		if(LL_GPIO_IsInputPinSet(PWSTG_PGOOD_DI_GPIO_Port, PWSTG_PGOOD_DI_Pin))
#else
		if(!LL_GPIO_IsInputPinSet(PWSTG_PGOOD_DI_GPIO_Port, PWSTG_PGOOD_DI_Pin))
#endif
		{
			ErrorResponse(ERRC_SYSTEM_ERROR, ERST_GATEDRV_UVLO);
			FlagMeasurementState = Meas_State_Deinit;
			break;
		}

		if(GetTick() < MeasurementNextStepTime)break;

		SamplingTiming.SetMultiplier = 0;
		SamplingTiming.SetSampleTime = SamplingTiming.FastSampleTime;

		CalcADCSamplingSettings(SamplingTiming.SetSampleTime);

		MeasurementNextStepTime += SamplingTiming.CoolingTime;
		FlagMeasurementState = Meas_State_PrepCooling;

		break;
	case Meas_State_Cooling:

		LL_GPIO_ResetOutputPin(PWSTG_PWR_EN_DO_GPIO_Port, PWSTG_PWR_EN_DO_Pin);
		if(GetTick()< MeasurementNextStepTime)break;

		FlagMeasurementState = Meas_State_Deinit;

		break;
	case Meas_State_Deinit:					// cooling time is over, stop the whole system
		DISABLE_TIMER;												// Disable the timer, to stop the ADC
		Deinit_ADC();
		LL_GPIO_ResetOutputPin(PWSTG_EN_DO_GPIO_Port, PWSTG_EN_DO_Pin);		// Disable the powerstage to shut down the heating current
		LL_GPIO_ResetOutputPin(PSU_EN_DO_GPIO_Port, PSU_EN_DO_Pin);			// Disable the power supply to minimize parasitic effects through the hot powerstage
		FlagMeasurementState = Meas_State_CloseLog;					// Tell the logging routine to write all data including the last block
		//break;
	case Meas_State_CloseLog:
		// Write the rest of the buffer
		do{
			ADC_BufferReadBlock = Log_WrittenBlocks % ADC_BFR_BLOCKS;
			WriteBlockToFile(ADC_BufferReadBlock,Log_WrittenBlocks);
			Log_WrittenBlocks++;
		}while(Log_WrittenBlocks <= ADC_TotalBlocks);

		WriteFileFooterToFile(&littlefs, &file, ADC_CoolingStartBlock, ADC_TotalBlocks);
		EvalLFSError(lfs_file_sync(&littlefs, &file));
		EvalLFSError(lfs_file_close(&littlefs, &file));

		if( LFS_ret < 0){
			ErrorResponse(ERRC_FILE_SYSTEM, (uint8_t)LFS_ret);
		}

		ADC_CoolingStartBlock =0;
		Log_WrittenBlocks = 0;
		RTC_read_time(&Time);
		UART_printf("Measurement completed!\n");

		FlagMeasurementState = Meas_State_Idle;
		break;
	case Test_State_Init:					// check for the flag to start the calibration

		if(FlashMemoryAvailable <= 0){
			ErrorResponse(ERRC_FILE_SYSTEM, ERST_NO_FLASH_MEMORY);
			FlagMeasurementState = Meas_State_Idle;
			break;
		}

		LL_GPIO_SetOutputPin(PWSTG_PWR_EN_DO_GPIO_Port, PWSTG_PWR_EN_DO_Pin);		// Enable the gate driver supply
		LL_GPIO_SetOutputPin(PSU_EN_DO_GPIO_Port, PSU_EN_DO_Pin);					// Enable the output of the Main Power Supply

		Setup_TIM1(TIM_Mode_Cal);

		SamplingTiming.SetMultiplier = SamplingTiming.MaxTimeMultiplier;
		SamplingTiming.SetSampleTime = (SamplingTiming.FastSampleTime << SamplingTiming.SetMultiplier);
		CalcADCSamplingSettings(SamplingTiming.SetSampleTime);

		Init_ADC_DMA(ADC1_DIODE1_PGA_IN_AI_CH, ADC2_DIODE2_IN_AI_CH, ADC3_DIODE2_IN_AI_CH, ADC4_CURRENT_IN_AI_CH,(uint32_t)&ADC_Buffer12, (uint32_t)&ADC_Buffer34);

		ENABLE_TIMER;						// Enable the timer for ADC sample rate generation

		MeasurementStartTime = GetTick();	// Calculate the time when the next Measurement step shall be started
		MeasurementNextStepTime = MeasurementStartTime + SamplingTiming.TestSampleTime;

		FlagMeasurementState = Test_State_Cal;	// Set the step for the StateMachine to the next step

		break;
	case Test_State_Cal:
		if(GetTick()< MeasurementNextStepTime) break;

		MeasurementNextStepTime += SamplingTiming.TestSampleTime;

		PrintLastADC=true;

		break;
	case Test_State_DeInit:

		DISABLE_TIMER;									// Disable the timer, to stop the ADC
		Deinit_ADC();
		LL_GPIO_ResetOutputPin(PWSTG_EN_DO_GPIO_Port, PWSTG_EN_DO_Pin);		// Disable the powerstage to shut down the heating current
		LL_GPIO_ResetOutputPin(PSU_EN_DO_GPIO_Port, PSU_EN_DO_Pin);			// Disable the power supply to minimize parasitic effects through the hot powerstage
		LL_GPIO_ResetOutputPin(PWSTG_PWR_EN_DO_GPIO_Port, PWSTG_PWR_EN_DO_Pin); // Disable the gate driver power supply

		FlagMeasurementState = Test_State_Exit;	 // Set the step for the StateMachine to the next step

		break;
	case Test_State_Exit:

		ADC_CoolingStartBlock =0;
		Log_WrittenBlocks = 0;

		RTC_read_time(&Time);
		UART_printf("Measurement completed! \n");

		FlagMeasurementState = Meas_State_Idle;
		break;
	case Temp_State_Init:
		break;
	case Temp_State_Heat:
		break;
	case Temp_State_Settle:
		break;
	case Temp_State_Measure:
		break;
	case Temp_State_Deinit:
		break;
	default:
		break;
	}

	// Data logging loop
	if (FlagMeasurementState > Meas_State_InitMeasFile){
		if ((ADC_TotalBlocks>0) && (Log_WrittenBlocks < ADC_TotalBlocks) && (FlagMeasurementState < Meas_State_CloseLog) ){
			LD2_GPIO_Port->BSRR = LD2_Pin;
			LL_GPIO_SetOutputPin(DBG_IO3_GPIO_Port, DBG_IO3_Pin);
			LL_GPIO_ResetOutputPin(DBG_IO4_GPIO_Port, DBG_IO4_Pin);

			ADC_BufferReadBlock = Log_WrittenBlocks % ADC_BFR_BLOCKS;	// Calculate the virtual Block number
			if((Log_WrittenBlocks + ADC_BFR_BLOCKS) < ADC_TotalBlocks ){
				//ErrorResponse(ERRC_SYSTEM_ERROR, ERST_ADC_BUFFER_OVERRUN);
			}

			if(WriteBlockToFile(ADC_BufferReadBlock,Log_WrittenBlocks)){
				Log_WrittenBlocks++;
			}
			else{
				ADC_TotalBlocks--;	// Some botch to fix the mysterious behaviour of 100 samples offset
				LL_GPIO_SetOutputPin(DBG_IO4_GPIO_Port, DBG_IO4_Pin);
			}

			LL_GPIO_ResetOutputPin(DBG_IO3_GPIO_Port, DBG_IO3_Pin);

			LD2_GPIO_Port->BRR = LD2_Pin;
		}

		if(GetTick() > NextOutput){		// Measurement is running
			if(OperatingMode == Mode_Normal){
				WriteTemperaturesToFile();
			}

			if((GetTick() - NextOutput) < MEASURE_DATA_UPDATE_TIME){
				NextOutput += MEASURE_DATA_UPDATE_TIME;
			}
			else{	// catch up with the timer
				NextOutput = GetTick() + MEASURE_DATA_UPDATE_TIME;
			}
			Meas_RunTime = GetTick()-Meas_StartTime;
			PrintLastADC=true;
		}
	}

	if(PrintLastADC){

		ADC_BFR_idx = (ADC_BFR_BLOCKS*ADC_BFR_SIZE - DMA1_Channel1->CNDTR)-1;
		if( ADC_BFR_idx <1)
			ADC_BFR_idx = ADC_BFR_BLOCKS*ADC_BFR_SIZE-1;

		adc_val.ADC_Reg = ADC_Buffer12[(uint16_t)ADC_BFR_idx];
		UART_printf("#M;%d;%d;%d;%d;",FlagMeasurementState,ADC_PGA_Setting[(ADC_TotalBlocks)% ADC_BFR_BLOCKS],adc_val.ADC_Val[0],adc_val.ADC_Val[1]);

		adc_val.ADC_Reg = ADC_Buffer34[(uint16_t)ADC_BFR_idx];
		UART_printf("%d;%d",adc_val.ADC_Val[0],adc_val.ADC_Val[1]);

		for(uint8_t TKidx =0; TKidx<MAX6675_DEVICES;TKidx++)
		{
			UART_printf(";%.2f",Temp_TypeK[TKidx]);
		}
		UART_printf("\n");
	}

	if(LFS_ret<0 || GlobalWriteErrorFlag <0){
		GlobalWriteErrorFlag=0;
		ErrorResponse(ERRC_SYSTEM_ERROR, ERST_FILE_WRITE_ERR);
	}
}


/**************************************************************************/
/*!
    @brief  Write function that brings all data from the memory to the SD card
    @param  uint8_t ReadBlock				Block from the circular buffer that will be written to the SD card
    @param  uint32_t TotalWrittenBlocks		Total Number of Blocks written to the SD card
    @returns 1 if block was written, 0 if DMA is still in progress on the requested block
*/
/**************************************************************************/
uint8_t WriteBlockToFile(uint8_t ReadBlock, uint32_t TotalWrittenBlocks)
{
	uint16_t ADC_Idx =0;


	// calculate the borders of the current block
	uint16_t Block_Start = ReadBlock * ADC_BFR_SIZE;
	uint16_t Block_End = (ReadBlock+1) * ADC_BFR_SIZE;

	// read the DMA counter register and calculate the "forward" value
	uint16_t DMA_CurrentPos = (ADC_BFR_BLOCKS*ADC_BFR_SIZE) - DMA1_Channel1->CNDTR;
	int LFS_ret = 0;

	if(DMA_CurrentPos > Block_End || DMA_CurrentPos < Block_Start)	// check if the DMA counter is out of the way...
	{
		LL_GPIO_SetOutputPin(DBG_IO2_GPIO_Port, DBG_IO2_Pin);
		// format every sample into a line and print it onto the SD card. (single utoa's are ~50% faster than one sprintf)
		LFS_ret = LFS_WRITE_STRING(&littlefs, &file, "#B;");	// Block Number

		utoa(TotalWrittenBlocks,LogWriteBfr,10);
		LFS_ret = LFS_WRITE_STRING(&littlefs, &file, LogWriteBfr);

		LFS_ret = LFS_WRITE_STRING(&littlefs, &file, ";\n");
		LFS_ret = LFS_WRITE_STRING(&littlefs, &file, "#P;");	// PGA Setting

		utoa(ADC_PGA_Setting[ReadBlock],LogWriteBfr,10);
		LFS_ret = LFS_WRITE_STRING(&littlefs, &file, LogWriteBfr);
		LFS_ret = LFS_WRITE_STRING(&littlefs, &file, ";\n");

		union ADC_conv ADC_RegVal;
		for(ADC_Idx = Block_Start; ADC_Idx < Block_End; ADC_Idx++){

			ADC_RegVal.ADC_Reg = ADC_Buffer12[ADC_Idx];

			utoa(ADC_RegVal.ADC_Val[0],LogWriteBfr,10);
			LFS_ret = LFS_WRITE_STRING(&littlefs, &file, LogWriteBfr);
			LFS_ret = LFS_WRITE_STRING(&littlefs, &file, ";");
			utoa(ADC_RegVal.ADC_Val[1],LogWriteBfr,10);
			LFS_ret = LFS_WRITE_STRING(&littlefs, &file, LogWriteBfr);

			LFS_ret = LFS_WRITE_STRING(&littlefs, &file, ";");

			ADC_RegVal.ADC_Reg = ADC_Buffer34[ADC_Idx];

			utoa(ADC_RegVal.ADC_Val[0],LogWriteBfr,10);
			LFS_ret = LFS_WRITE_STRING(&littlefs, &file, LogWriteBfr);
			LFS_ret = LFS_WRITE_STRING(&littlefs, &file, ";");
			utoa(ADC_RegVal.ADC_Val[1],LogWriteBfr,10);
			LFS_ret = LFS_WRITE_STRING(&littlefs, &file, LogWriteBfr);
			LFS_ret = LFS_WRITE_STRING(&littlefs, &file, ";\n");
		}
		if(LFS_ret <0){
			GlobalWriteErrorFlag =1;
		}
		LL_GPIO_ResetOutputPin(DBG_IO2_GPIO_Port, DBG_IO2_Pin);
		return 1;
	}
	else{
		return 0;
	}
}

/**************************************************************************/
/*!
  * @brief  Writes the latest measured temperatures to the logging file
  * @retval None
*/
uint8_t WriteTemperaturesToFile(void){

	int LFS_ret = 0;

	EvalLFSError(LFS_WRITE_STRING(&littlefs, &file, "#T;"));	// Thermocouples
	for(uint8_t TKidx =0; TKidx<MAX6675_DEVICES;TKidx++)
	{
		//utoa(Temp_TypeK[TKidx],LogWriteBfr,10);
		sprintf(LogWriteBfr,"%.2f",Temp_TypeK[TKidx]);
		EvalLFSError(LFS_WRITE_STRING(&littlefs, &file, LogWriteBfr));
		EvalLFSError(LFS_WRITE_STRING(&littlefs, &file, ";"));
	}
	EvalLFSError(LFS_WRITE_STRING(&littlefs, &file, "\n"));

	if(LFS_ret <0){
		GlobalWriteErrorFlag =1;
	}
	return 1;

}
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

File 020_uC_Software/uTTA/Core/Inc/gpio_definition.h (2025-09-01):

/*
 * gpio_definition.h
 *
 *  Created on: Oct 14, 2024
 *      Author: wtronics
 */

#ifndef INC_GPIO_DEFINITION_H_
#define INC_GPIO_DEFINITION_H_

#include "config_parameters.h"

#ifdef __cplusplus
extern "C" {
#endif


//Button 1 port
#define Btn_Start_Stop_Pin LL_GPIO_PIN_13
#define Btn_Start_Stop_GPIO_Port GPIOC
// On Board LED
#define LD2_Pin LL_GPIO_PIN_5
#define LD2_GPIO_Port GPIOA


// Debug IO1 port
#define DBG_IO1_Pin LL_GPIO_PIN_0
#define DBG_IO1_GPIO_Port GPIOC
// Debug IO2 port
#define DBG_IO2_Pin LL_GPIO_PIN_1
#define DBG_IO2_GPIO_Port GPIOC
// Debug IO3 port
#define DBG_IO3_Pin LL_GPIO_PIN_2
#define DBG_IO3_GPIO_Port GPIOC
// Debug IO4 port
#define DBG_IO4_Pin LL_GPIO_PIN_3
#define DBG_IO4_GPIO_Port GPIOC
// Debug Pin for Sample time generation timer
#define TIM_DBG_PO_Pin LL_GPIO_PIN_10
#define TIM_DBG_PO_GPIO_Port GPIOA


// Enable Powerstage pin
#define PWSTG_EN_DO_Pin LL_GPIO_PIN_0
#define PWSTG_EN_DO_GPIO_Port GPIOA
// Readback pin of powerstage power supply good signal
#define PWSTG_PGOOD_DI_Pin LL_GPIO_PIN_1
#define PWSTG_PGOOD_DI_GPIO_Port GPIOA
// Enable pin of external power supply
#define PSU_EN_DO_Pin LL_GPIO_PIN_4
#define PSU_EN_DO_GPIO_Port GPIOA
// Gate driver power supply enable
#define PWSTG_PWR_EN_DO_Pin LL_GPIO_PIN_0
#define PWSTG_PWR_EN_DO_GPIO_Port GPIOB


// Amplifier Gain Switching outputs
#define GAIN_B0_DO_Pin LL_GPIO_PIN_6
#define GAIN_B0_DO_GPIO_Port GPIOA
#define GAIN_B1_DO_Pin LL_GPIO_PIN_7
#define GAIN_B1_DO_GPIO_Port GPIOA


// Analog inputs for measurement
#define PGA_DIODE3_AI_Pin LL_GPIO_PIN_1
#define PGA_DIODE3_AI_GPIO_Port GPIOB
#define PGA_DIODE2_AI_Pin LL_GPIO_PIN_2
#define PGA_DIODE2_AI_GPIO_Port GPIOB
#define PGA_DIODE1_AI_Pin LL_GPIO_PIN_11
#define PGA_DIODE1_AI_GPIO_Port GPIOB
#define CURR_MEAS_AI_Pin LL_GPIO_PIN_14
#define CURR_MEAS_AI_GPIO_Port GPIOB
#define PGA_DIODE4_AI_Pin LL_GPIO_PIN_15
#define PGA_DIODE4_AI_GPIO_Port GPIOB


// SPI Interface for flash memory
#define FLASH_SPI_SCK_Pin LL_GPIO_PIN_10
#define FLASH_SPI_SCK_GPIO_Port GPIOC
#define FLASH_SPI_MISO_Pin LL_GPIO_PIN_11
#define FLASH_SPI_MISO_GPIO_Port GPIOC
#define FLASH_SPI_MOSI_Pin LL_GPIO_PIN_12
#define FLASH_SPI_MOSI_GPIO_Port GPIOC
#define FLASH_SPI_CS_Pin LL_GPIO_PIN_2
#define FLASH_SPI_CS_GPIO_Port GPIOD


/// Type K temperature sensor  and DAC  SPI + Chip select lines
// SCK Line
#define AUX_SPI_SCK_Pin LL_GPIO_PIN_8
#define AUX_SPI_SCK_GPIO_Port GPIOC
// MISO Line
#define AUX_SPI_MISO_Pin LL_GPIO_PIN_9
#define AUX_SPI_MISO_GPIO_Port GPIOC
// MOSI Line
#define AUX_SPI_MOSI_Pin LL_GPIO_PIN_12
#define AUX_SPI_MOSI_GPIO_Port GPIOA

// CS-Lines for thermocouple transducers
#define AUX_SPI_TC0_CSN_Pin          LL_GPIO_PIN_9
#define AUX_SPI_TC0_CSN_GPIO_Port    GPIOB
#define AUX_SPI_TC1_CSN_Pin          LL_GPIO_PIN_5
#define AUX_SPI_TC1_CSN_GPIO_Port    GPIOC
#define AUX_SPI_TC2_CSN_Pin          LL_GPIO_PIN_8
#define AUX_SPI_TC2_CSN_GPIO_Port    GPIOB
#define AUX_SPI_TC3_CSN_Pin          LL_GPIO_PIN_6
#define AUX_SPI_TC3_CSN_GPIO_Port    GPIOC

// CS-line for DAC
#define AUX_SPI_DAC_CSN_Pin          LL_GPIO_PIN_11
#define AUX_SPI_DAC_CSN_GPIO_Port    GPIOA




// USART RX/TX pins
#define USART_TX_Pin LL_GPIO_PIN_2
#define USART_TX_GPIO_Port GPIOA
#define USART_RX_Pin LL_GPIO_PIN_3
#define USART_RX_GPIO_Port GPIOA


// External debugger connection
#define TMS_Pin LL_GPIO_PIN_13
#define TMS_GPIO_Port GPIOA
#define TCK_Pin LL_GPIO_PIN_14
#define TCK_GPIO_Port GPIOA
#define SWO_Pin LL_GPIO_PIN_3
#define SWO_GPIO_Port GPIOB


#ifndef NVIC_PRIORITYGROUP_0
#define NVIC_PRIORITYGROUP_0         ((uint32_t)0x00000007) /*!< 0 bit  for pre-emption priority,
                                                                 4 bits for subpriority */
#define NVIC_PRIORITYGROUP_1         ((uint32_t)0x00000006) /*!< 1 bit  for pre-emption priority,
                                                                 3 bits for subpriority */
#define NVIC_PRIORITYGROUP_2         ((uint32_t)0x00000005) /*!< 2 bits for pre-emption priority,
                                                                 2 bits for subpriority */
#define NVIC_PRIORITYGROUP_3         ((uint32_t)0x00000004) /*!< 3 bits for pre-emption priority,
                                                                 1 bit  for subpriority */
#define NVIC_PRIORITYGROUP_4         ((uint32_t)0x00000003) /*!< 4 bits for pre-emption priority,
                                                                 0 bit  for subpriority */
#endif

#ifdef __cplusplus
}
#endif

#endif /* INC_GPIO_DEFINITION_H_ */

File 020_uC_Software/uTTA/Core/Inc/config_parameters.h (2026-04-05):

/*
 * config_parameters.h
 *
 *  Created on: Oct 14, 2024
 *      Author: wtronics
 */

#ifndef INC_CONFIG_PARAMETERS_H_
#define INC_CONFIG_PARAMETERS_H_

/* Includes ------------------------------------------------------------------*/
#include "stm32f3xx_ll_adc.h"
#include "stm32f3xx_ll_dma.h"
#include "stm32f3xx_ll_rcc.h"
#include "stm32f3xx_ll_bus.h"
#include "stm32f3xx_ll_system.h"
#include "stm32f3xx_ll_exti.h"
#include "stm32f3xx_ll_cortex.h"
#include "stm32f3xx_ll_utils.h"
#include "stm32f3xx_ll_pwr.h"
#include "stm32f3xx_ll_spi.h"
#include "stm32f3xx_ll_tim.h"
#include "stm32f3xx_ll_usart.h"
#include "stm32f3xx_ll_gpio.h"
#include "stm32f3xx_ll_utils.h"

#include "stm32f3xx_it.h"

#if defined(USE_FULL_ASSERT)
#include "stm32_assert.h"
#endif /* USE_FULL_ASSERT */

#include "math.h"


#define UTTA_OWNER "WK"
#define UTTA_SERIAL_NO "001"

// Define if you have an early hardware of the power PCB (before Version 1.0) or after (because of inverted Power Good Signal from Gatedriver)
//#define EARLY_HW_POWER_BOARD
#define HW_MEASURE_BOARD_BELOW_V2P2				// uncomment in case of an older Measure Board Hardware (Active and Error LED were twisted)
//#define ENABLE_TIMER_DEBUGGING


#define UTTA_SW_VERSION "2.6"
#define UMF_FILEVERSION "3.5"

#define CHANNEL_NAME_MAX_LENGTH 31								// Max Length of the channel Name
#define MAX_DUT_NAME_LENGTH 50 + 5 		// Max length of the Dut name + 4 characters for file extension (.umf)

// Handle Definition for Flash-SPI and UART
#define SD_SPI_HANDLE 		SPI3
#define UART_HANDLE 		USART2
#define ADC_TIMER_HANDLE  	TIM3
#define ADC_MASTER_HANDLE	ADC1


// ADC Buffer definition
#define ADC_BFR_BLOCKS 20
#define ADC_BFR_SIZE   250

#define ADC1_DIODE1_PGA_IN_AI_CH 14
#define ADC2_DIODE2_IN_AI_CH     12
#define ADC3_DIODE2_IN_AI_CH     1
#define ADC4_DIODE2_IN_AI_CH     5
#define ADC4_CURRENT_IN_AI_CH    4



#define PRESC_SAMPLECLOCK_INITIAL 8000000UL
#define ADC_MAX_SAMPLERATE        2000000UL
#define ADC_MIN_SAMPLERATE         100000UL

#define SAMPLECLOCK_MASTER_FREQ 72000000UL
#define PRESCALER_UPSCALE_INITIAL SAMPLECLOCK_MASTER_FREQ/PRESC_SAMPLECLOCK_INITIAL

#define ADC_MAX_MULTIPLIER  17UL
#define ADC_DEF_SAMPLETIME	PRESC_SAMPLECLOCK_INITIAL/ADC_MAX_SAMPLERATE


#define MEASURE_DATA_UPDATE_TIME	500UL
#define MEASURE_TEMP_UPDATE_TIME	300UL

#ifdef DEBUG_SHORT_TIMES
	#define MEAS_DEF_PREHEATING_TIME	6000UL
	#define MEAS_DEF_HEATING_TIME		10000UL
	#define MEAS_DEF_COOLING_TIME		36000UL
#else
	#define MEAS_DEF_PREHEATING_TIME	60000UL
	#define MEAS_DEF_HEATING_TIME		2400000UL
	#define MEAS_DEF_COOLING_TIME		3600000UL
#endif

#define MEAS_MIN_PREHEATING_TIME   	30000UL		// 30 seconds
#define MEAS_MAX_PREHEATING_TIME   	21600000UL	// 6 hours	--> extended max preheating time to do calibration of TSP

#define MEAS_MIN_HEATING_TIME      	60000UL		// 60 seconds --> to skip heating and cooling phase you can also set the value to 0
#define MEAS_MAX_HEATING_TIME      	10800000UL	// 3 hours

#define MEAS_MIN_COOLING_TIME      	60000UL		// 60 seconds
#define MEAS_MAX_COOLING_TIME      	21600000UL	// 6 hours

#define TEST_DEF_SAMPLE_TIME		250UL
#define TEST_MAX_SAMPLE_TIME		2500UL
#define TEST_MIN_SAMPLE_TIME		25UL

#define PGA_DEF_GAIN				1
#define PGA_MIN_GAIN				0
#define PGA_MAX_GAIN				3

// DAC Default values when in calibrated state
#define ISEN_DEF_VALUE_mA        5.0f
#define VOFFS0_DEF_VALUE_V	    -0.2f
#define VOFFS1_3_DEF_VALUE_V	-0.3f

// DAC Default values when in non-calibrated state
#define ISEN_DEF_VALUE_RAW        32768.0f	// roughly 5.6mA
#define VOFFS0_DEF_VALUE_RAW	  18000.0f	// roughly -0.2V
#define VOFFS1_3_DEF_VALUE_RAW	  18000.0f	// roughly -0.2V


#ifdef HW_MEASURE_BOARD_BELOW_V2P2
	// Status LEDs
	// Active
	#define ACTIVE_LED_DO_Pin LL_GPIO_PIN_13
	#define ACTIVE_LED_DO_GPIO_Port GPIOB
	// Status
	#define STATUS_LED_DO_Pin LL_GPIO_PIN_5
	#define STATUS_LED_DO_GPIO_Port GPIOB
	// Error
	#define ERROR_LED_DO_Pin LL_GPIO_PIN_10
	#define ERROR_LED_DO_GPIO_Port GPIOA


#else
	// Status LEDs
	// Active
	#define ACTIVE_LED_DO_Pin LL_GPIO_PIN_10
	#define ACTIVE_LED_DO_GPIO_Port GPIOA
	// Status
	#define STATUS_LED_DO_Pin LL_GPIO_PIN_5
	#define STATUS_LED_DO_GPIO_Port GPIOB
	// Error
	#define ERROR_LED_DO_Pin LL_GPIO_PIN_13
	#define ERROR_LED_DO_GPIO_Port GPIOB

#endif


//#define MODE_NORMAL      0
//#define MODE_TESTMODE    1
//#define MODE_TEMPCONTROL 2

typedef enum {
	 Mode_Normal,
	 Mode_Test,
	 Mode_TempControl
} DeviceModes_t;

typedef struct PGA_Gain_{
	uint8_t Set;
	uint8_t Cooling;
	uint8_t Heating;
} PGA_t;

typedef struct Sampling_Timing_{
	uint32_t FastSampleTime;
	float    FastSampleRate;
	uint32_t MaxTimeMultiplier;
	uint32_t SetSampleTime;
	uint32_t SetMultiplier;
	uint32_t PreHeatingTime;
	uint32_t HeatingTime;
	uint32_t CoolingTime;
	uint32_t TestSampleTime;
} Timing_t;
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

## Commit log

2024-08-07 Fixed issue in calibration mode of LV software
2024-08-07 Update of path within file
    [uTTA_HTERM_Configuration.cfg]
2024-08-22 Stability Improvement
    General improvement of LabView VI stability. Added Features: File Manager and Calibration Manager.
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2024-09-02 Added ADC Overrange Indicators
2024-09-30 Minor Cleanup of Design
    [uTTA_V1_Measure.brd, uTTA_V1_Measure.sch, uTTA_V1_Power.brd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]
2024-09-30 Hardware Version 2 of the Measure Board
    Improved adjustability of current sources ( through DAC or manual)
    Separate offset control for Heated and unheated channels.
    More Flash on Board
    Rearranged connectors
    Added indicator LEDs
    [uTTA_V2_Measure.brd, uTTA_V2_Measure.sch]
2024-09-30 Minor Update on calibration routine
2024-10-01 Fixed paste mask issue for test points in the gerber output
2024-10-01 Reload of some components from library, after fix of paste mask issue
    [uTTA_V2_Measure.brd, uTTA_V2_Measure.sch]
2024-10-01 Schematic of Measure Board V2
2024-10-21 Optimization of Testpoints for Calibration
    [uTTA_V2_Measure.brd, uTTA_V2_Measure.sch]
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2024-10-21 Pinning for Measure V2 Board
    [STM32F303_Pinning.xlsx]
2024-10-28 Improved over HW2.0
    Removed manual potentiometers
    Added pinheaders for easier calibration
    [uTTA_V2.1_Measure.brd, uTTA_V2.1_Measure.sch]
2024-10-28 Added latest commands
    [uTTA_HTERM_Configuration.cfg]
2024-11-10 Rework of GPIO Init
    [gpio_func.c]
2024-11-10 Update SCPI_server.cpp
    Added new SCPI commands for File Upload and Calibration Data
    Removed functions for Sampling Timing
2024-11-10 Update spic_func.c
    Update of SPI Pins
2024-11-15 Added surpression of first sample of measurement
    The first sample is always zeros, therefore all plot get disturbed by it
2025-01-20 update of OpAmp Selection
    [uTTA_V2.1_Measure.brd, uTTA_V2.1_Measure.sch]
2025-01-20 Update of calibration routine
    - fixed minor issues in sampling from uTTA
    - added default calibration test selection to GUI
2025-01-20 Changed Name of Error Code
    [ErrorCodes.h]
2025-01-20 Flash related no update
    - Added prevention that uC locks up when flash memory is not available.
    - no flash will now return 3.001 Flash Memory not available
    [main.cpp]
2025-01-20 Add of calibration mode
    Added input when VI is run in calibration mode to prevent unnecessary scaling
2025-01-22 Total rework for new umf files
    removed support for file before file version 3.0
    optimized parsing of measurement files
    added new routine for reading calibration files (ucf)
    update of calibration value write
2025-02-09 Update of Config Constants
    Update of measurement file file version
    Update of Firmware Version
    Added constant for the uTTAs owner
    Added constant for the device serial number
2025-02-09 Added function argument
    Added additional parameter to funtion Read_CalibrationFromFlash to disable serial output while reading the calibration file
2025-02-09 Add of Error Codes
    Added error code for missing calibration file
    [ErrorCodes.h]
2025-02-09 Add of function to read calibration from device
2025-02-09 Added measurement start check
    Added step to check if a valid calibration is available before starting the measuremnt
2025-02-09 Update uTTA_Main.vi
    Added a tooltip hints. Calibration is now loaded from the device
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2025-02-09 Cleanup of unused code and unnessesary print statements
2025-02-10 Bugfix in MAX6675 soft SPI
    corrected erroneous shifting and scaling
    [MAX6675.c]
2025-02-23 Serial Communication improvement
    Improved stability of serial communication during measurements by adding text qualifiers to the device responses.
2025-02-23 Create uTTA_QualifiyResponse.vi
    Searches the received serial data for the response required as answer for the current command
2025-02-23 Pinnumbering corrected
    Corrected Pin Numbering of Jumpers
    [uTTA_V2.1_Measure.brd, uTTA_V2.1_Measure.sch]
2025-03-02 Change of Offset Voltage decoupling resistors
    Changed decoupling resistors from 10 Ohm to 0Ohm to reduce incluence on measurement results
    [uTTA_V2.1_Measure.brd, uTTA_V2.1_Measure.sch]
2025-03-02 Update after change of resistors
2025-03-03 Code cleanup
    Changed name mode from calibration to testmode
2025-03-05 Renamed calibration mode to test mode
2025-03-05 Fixed wrong function parameter types
    [ad56x4.c]
2025-03-09 Fixed max variable range comparison
    [ad56x4.c]
2025-03-09 Changed temperature reporting to float, added basis for temperature control
2025-03-09 Added Error code for too large files
    [ErrorCodes.h]
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2025-03-09 Update to new temperature reporting format from file version 3.3
2025-04-08 Fixed wrong channel count in IF
    [SCPI_server.cpp]
2025-04-11 Update of ADC filter RC-values
    Changed ADC filter values to reduce effect of sampling droop
    [uTTA_V2.1_Measure.brd, uTTA_V2.1_Measure.sch]
2025-04-14 Update on RC-filter values for current measurement
    [uTTA_V1_Power.brd, uTTA_V1_Power.sch]
2025-05-06 Update to uTTA Version 2.2
    Full update of both PCBs to HW Version 2.2:
    Removed spare FLASH Memory
    Adjusted Position of LEDs and Buttons
    Cleanup of layout
    [uTTA_V1_Measure.brd, uTTA_V1_Measure.sch, uTTA_V2.1_Measure.csv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]
2025-05-06 Fixed misleading naming of calibration factor
    Change name of third calibration factor from CubGain to QuadGain as it only reflect the quadratic gain value
2025-05-06 Update of BOM for uTTA_Power_V2.2
    [uTTA_V1_Power.csv, uTTA_V2.2_Power.csv]
2025-05-06 Create uTTA_Device_Calibration.xlsx
    First draft of a calibration result sheet to help and guide calibration
    [uTTA_Device_Calibration.xlsx]
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2025-05-19 Added error handling for wrong files
    [uTTA_Postprocess_Measurement.py]
2025-05-19 Tweaked file to be recognized as calibration measurement
2025-05-26 Bugfix on FIle check
    [uTTA_Postprocess_Measurement.py]
2025-06-30 Bugfix
    replaced duplicate voltage plot in 1,1 with current plot
    [uTTA_Postprocess_Measurement.py]
2025-08-27 Delete uTTA_V1_Lower_Housing.3mf
    Removal because of outdated design
    [uTTA_V1_Lower_Housing.3mf]
2025-08-27 New housing design to fit all PCBs into one housing
    [Baseplate.3mf, Battery_Lid.3mf, Sliding_Wall.3mf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]
2025-09-01 Swapped LEDs LED1 and LED3 because of twisted naming
    [uTTA_V2.2_Measure.brd]
2025-09-01 Added Configuration Parameters
    Added new configuration parameters (HW_MEASURE_BOARD_BELOW_V2P2 and ENABLE_TIMER_DEBUGGING) for better configurability between buggy HW Revisions.
    Moved "End User Configurable" Parameters to top of file.
    [config_parameters.h]
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2025-09-01 Added Features & Bugfix
    Added Status LED outputs
    Hopefully fixed bug with ADC & DMA on repeated measurements
    [main.cpp]
2025-09-06 Update uTTA_data_import.py
    Added function to check if the block length of the adc and find block with missing samples
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2025-09-18 Added readouts for device name and file version
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2025-09-30 Added frame for future parameters to be stored
2025-10-04 fixed wrong configuraion of configparser
    new settings destroyed case sensitive keys
2025-10-19 First basic prototype of the HTML reporting function
2025-10-19 Added Error Handling on Plot Axis
    Added Error Handling when log plots contains negative values. In this case the Y-Axis scaling is switched to linear mode
2025-10-19 Added automatic error handling for negative values on log Y-Axis
2025-11-03 Fixed exported data
    raw adc values were exported instead of the zth curve
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2025-11-16 Added safety question to prevent unintended deletion of calibration file.
2025-11-16 Added new button to export t3i intermediate file
2025-11-22 Update to Revision 2.5.3
    Changed values of resistors for optocouplers (reduced LED current). Replaced 10 ohm input resistors with 0Ohm
    [uTTA_V2.2_Power.csv]
2025-11-22 changed resistor values
    Changed Values of R101 and R102 to 0 Ohm
    Changed value of R108 from 100 Ohm to 240 Ohm (to reduce optocoupler LED current)
    Changed value of R110 from 220 Ohm to 470 Ohm (to reduce LED current)
    [uTTA_V2.2_Power.brd, uTTA_V2.2_Power.sch]
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2026-01-04 removed outdated variants from design
    [uTTA_V2.2_Measure.brd, uTTA_V2.2_Measure.sch]
2026-01-04 Added missing response header
    [SCPI_server.cpp]
2026-01-06 Added output in case a calibration file is available
2026-01-06 Bugfix on detection of file exits (wrong comparison)
    [SCPI_server.cpp]
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2026-03-13 Placement & Style Improvements
    Changed placement from grid to pack.
    Added Axis labels on x-Axis for every decade
2026-03-18 Added support for logging + Bugfix
    Bugfixed coupling calculation. Calculation results were switching signedness after each change in the interpolation window
2026-03-18 Added logging support
    Removed old print to console statements and replaced them by logger statements
2026-03-29 Increased Max UART Buffer length (just for safety)
2026-03-29 Change from sprintf to snprintf
    Changed to snprintf to prevent the system from buffer overflow.
    [dev_cal.c]
2026-06-04 Update the way the current channel is treated. Played around with lucy richardson deconvolution
2026-06-26 Fixed wrong data assignment to plot
    Lower plot showed voltages instead of temperatures.
2026-07-05 Added Calibration Report, fixed type hints for interpolated data
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2026-07-05 Added Calibration Report, Added Constants for column numbers
2026-07-10 Fixed bug in detection if measurement file exists
    [main.cpp]
2026-07-28 Support raw_mode for import and plotting
    Add a raw_mode flag (default 0) to UmfViewerApp and thread it through import and UI logic. When raw_mode != 0 the viewer shows raw input TSP/current measurement plots (add_input_tsp_measure_curve_plot, add_input_current_measure_curve_plot), skips calibration-dependent columns/processing, and omits heating/cooling calculations and calibrated TSP displays. Pass raw_mode into utta_data.import_data(...) and conditionally adjust meta info. This enables inspecting raw measurement curves without applying TSP calibration.
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2026-09-25 Fix of recently introduced bug
    added scaling by 1.000.000 on calibration values to scale from µV back to V

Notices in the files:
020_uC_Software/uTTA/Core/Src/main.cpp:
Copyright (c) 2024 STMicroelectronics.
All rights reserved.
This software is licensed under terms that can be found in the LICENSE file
